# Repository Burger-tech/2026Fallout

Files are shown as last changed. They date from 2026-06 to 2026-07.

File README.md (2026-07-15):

# Our 2026 HackClub Fallout Project
Presented by Tyler Bergsma and Andy He (With a TON of CAD help from Keegan O'Neil)

## Our Project

We decided to make a Nerf Rival shooting mecanum-drive differential-turret robot that has auto aiming built in. This came from a love of robotics from all of us, and also because we all enjoy Nerf battles and guns.  Here's an example of what we wanted the turret to look initially: 

whatwewanted

This is what our original thought concept was considering the features we wanted for our bot.

The next most meaningful part of the robot is the drivetrain, which we decided would use mecanum wheels to give our robot incredibly diverse and versatile movement. Paired with the strong 600RPM motors we plan to use, this should give us a very snappy and responsive bot. 
Because our robot will be mostly 3d-printed out of PETG, it should be very durable, and the underlying frame (made of aluminum) brings that up even more.
Our camera system on the robot should also be extremely robust, using 3 cameras in total- 2 for general operator vision and 1 to give an onbaord raspberry pi access to auto-aiming features so that the robot can aim fully autonomously. We plan to send the camera input back to Tyler's Steamdeck OLED for processing and for human controller input. Speaking of sending information back and forth, the robot will use a 2.4Ghz WiFi adapter to connect to a local network and allow it to stream video and control signals back and forth. This gives us extremely low latency and high quality video, as well as the added benefit of being able to possibly be connected to LTE farther down the line and be controlled from anywhere in the world.
To shoot the Rival rounds, we plan to use two flywheels and shoot them around ~110-120fps in total, giving them some kick for a relatively short spin up time and a small amount of downtime per shot.

Here's a picture of our full 3D model (done in onshape), to show what we mean by all that:

2026-06-16-220244_hyprshot

2026-06-16-220259_hyprshot

2026-06-16-220311_hyprshot

2026-06-16-220324_hyprshot

2026-06-16-220334_hyprshot

CAD OnShape Link: https://cad.onshape.com/documents/071289950c39e2528783d758/w/1973af73cf652c9bb88bcb7f/e/c3e7d5f0022195b47dc63524

And here's a screenshot of the base chasis that we plan to use:

base chasis

## Our Process

A full Bill of materials (BOM) can be found at the resources section at the bottom of our README.
To start off, first we figured out the major components we would use in our project and what mechanisms or devices we would use to bring our bot to life. This included creating a list of all of the parts we need with links, so that we'd also hopefully be able to find their dimensions and other specs. This took only around and hour with some very intensive googling and queries to Claude.
The next most important task was to CAD it upp! Our amazing half-team-member Keegan the CAD monster did all of this, creating the whole external structure of the bot including all of the mounts and such in OnShape.
Once our project gains monetary approval, we plan to 3D-print all of the parts we need from various colors of PETG on Tyler's A1-Mini and Ender-3. We also hope to possibly use the P2S in our robotics team lab to hopefully be able to print some of the larger parts quickly.

## US!

There are three of us working on this project. We are Tyler Bergsma, Keegan O'Neil, and Andy He. Unfortunately, Keegan won't be coming with us to Shenzen, but he was an AMAZING help to our lackluster CAD abilities. We're all from Denver, Colorado, U.S.A., and we all attend Chatfield Senior High, where we are a part of the schools local FIRST robotics team, [The Chargers (Team 9068)](https://Chatfieldrobotics.org). All three of us love robotics and mechanical/programming stuff, which is a huge part of why we chose to do what we did with this event. 

## BOM

- Drivetrain
    - JGB37-520 12V 600 RPM Motors
| Quantity: 4 | Price: $8.38 | Total: $33.52
    - BTS7960 43A H-Bridge Motor Driver
| Quantity: 1 (4 pack) | Price: $24.89 | Total: $24.89
    - 60mm Mecanum Wheel Omnidirectional Wheel Smart Robot Car Chassis with TT Motor N20G25
| Quantity: 1 (4 pack) | Price: $9.48 | Total: $9.48
    - SUNLU High Speed PETG Filament 1.75mm Bundle, Less Stringing PETG 3D Printer Filament, 2kg in Total, 1kg per Spool, 2 Pack, Blue+Red
| Quantity: 1 (2kg) | Price: $25.64 | Total: $25.64
    - ZDF Lipo battery 3S 11.1V 5000mAh 6000mah 8000mah 10000mah 12000mah 16000mah 25C 30C 50C For RC Helicopter Quadcopter
| Quantity: 1 | Price: $46.69 | Total: $46.69
    - GA12 N20 Encoder DC 6V Mini Micro Metal Gear DC Motor Gearwheel High Torque 100 RPM 7PPR Hall Sensor
| Quantity: 3 | Price: $0.99 | Total: $2.79
    - Emax ECO II Series 2306 1700KV 1900KV 2400KV Brushless Motor for RC FPV Drone Racing Quadcopter Spare Parts RC Parts
| Quantity: 1 (2 pack) | Price: $25.46 | Total: $25.46
    - TB6612 DRV8833 Dual Motor Driver 1A TB6612FNG for Arduino Microcontroller Better than L298N
| Quantity: 1 (3 pack) | Price: $0.99 | Total: $0.99
    - LittleBee 20A 30A BLHeli-S ESC Support DSHOT OneShot For 2-6S FPV Quadcopter
| Quantity: 1 (4 pack) | Price: $31.62 | Total: $31.62

- Electronics
    - Raspberry Pi Zero 2 WH Kit
| Quantity: 1 | Price: $41.99 | Total: $41.99
    - Wi-Fi USB Dongle Adapter with Gain Antenna – Plug & Play for Linux (Tails, Ubuntu, Debian, Fedora, Mint, Arch) + Windows 11/10/8/7, Android & Mac | 2.4 GHz MT7601U Chipset 150 Mbps
| Quantity: 1 | Price: $17.99 | Total: $17.99
    - Arducam 5MP Camera for Raspberry Pi, 1080P HD OV5647 Camera Module V1 for Raspberry Pi5/4/3/3B+, and Other A/B Series
| Quantity: 1 (maybe 2-4) | Price: $6.99 | Total: $6.99
    - ESP32-CAM WiFi Module 2.4G Antenna ESP32 Serial to WiFi ESP32 CAM Development Board 5V Bluetooth with OV3660 / OV2640 Camera DIY
| Quantity: 2 | Price: $6.46 | Total: $12.92
    - Official Raspberry Pi Pico Board RP2040 Dual-Core 264KB ARM Low-Power Microcomputers High-Performance Cortex-M0+ Processor
| Quantity: 3 | Price: $0.99 | Total: $2.79
    - 1-10pcs PCA9685PW 16 Channel 12-Bit PWM Servo Shield Driver I2C Interface PCA9685 Module For Raspberry Pi
| Quantity: 1 | Price: $0.99 | Total: $0.99
    - 2-8PCS LM2596 Step-down Power Supply Module 3A 3.2V-46V DC to DC Voltage Regulator Module Buck Converter Power Supply Modules
| Quantity: 1 (4 pack) | Price: $9.26 | Total: $9.26
    - AC 220V 250RPM 300RPM 6 Channel 6 wires Capsule Slip Ring CIRCUITSx2A Slipring 12.5/22MM Mini Rotary Conductive Joint Connectors
| Quantity: 1 | Price: $0.99 | Total: $0.99
    - 14AWG XT60 Female Male Plug Battery Connector with Silicone Flexible Wire for RC Airplane Lipo Battery ESC FPV Drone Car Boat | Quantity: 1 (10 pack)
| Price: $12.50 | Total: $12.50
    - 5 Colors Flexible Silicone Wire 16 AWG Gauge Tinned Copper Stranded Wire 300V Cables Electronic Wire Cable
| Quantity: 1 (5 colors, 4 meters) | Price: $9.30 | Total: $9.30
    - 5 Colors Flexible Silicone Wire 22 AWG Gauge Tinned Copper Stranded Wire 300V Cables Electronic Wire Cable
| Quantity: 1 (5 colors, 10 meters) | Price: $0.99 | Total: $0.99

- Others
    - 25V DIP Aluminum Electrolytic Capacitor 100UF
| Quantity: 1 (40 pack) | Price: $0.99 | Total: $0.99
    - POKONBOY 300 Rounds Refill Pack Balls Ammo Compatible with Nerf Rival Gun, Foam Bullet Ball Replacement Refill Pack for Blasters Guns
| Quantity: 1 (300 count) | Price: $24.99 | Total: $24.99
    - 0.5" Hex Shaft Collars
| Quantity: 5 | Price: $2.99 | Total: $14.95
    - 0.500" Hex ID x 1.125" OD x 0.313" WD (Flanged Bearing) (WCP-0783)
| Quantity: 4 | Price: $2.99 | Total: $11.96
    - OV2640 160 degrees 850nm night version 940nm camera module 21MM 24PIN 0.5MM spacing
| Quantity: 1 | Price: $0.99 | Total: $0.99
    - 10/50pcs Small Bearings 2mm 3mm 4mm 5mm 6mm 7mm 8mm 9mm 10mm Bore 3x7x3 5x10x4 5x11x4 8x22x7 10x15x4 mm Miniature Bearing
| Quantity: 20 (10 8x12x3.5mm and 10 15x21x4mm| Price: $0.99 | Total: $0.99
    - 5Pcs 6903RS 12x28x8mm Motor Grade Cover Sealed Deep Groove Ball Bearing RS 52100 Chrome Steel ABEC-7
| Quantity: 1 (5 pack 6903RS 17x30x7) | Price: $0.99 | Total: $0.99
    - 1/2in Rounded Hex Shafts
| Quantity: 1 | Price: $10.50 | Total: $10.50
    - 4Pcs 6mm Coupling
| Quantity: 1 (4 pack) | Price: $0.82 | Total: $0.82

Total Cost: $382.41

## Zine Page
Turret Bot Zine Page (1)

## How to Replicate and Understanding

Ratios:
Base Differential gears: 5:1or 125:25
Internal to external: 102:27 or 34/9:1
Bevel gears: 1:1 or 20:20
Angle control: 100:16 or 6.25:1

coaxial/differential explanation:
The differential turret consists of two base gears, with one gear having only external teeth, and the other having both external and internal teeth. A separate gear is mounted to the gear that only has external teeth, but it is driven by the gear that has both internal and external gears. The gear that gets driven internally directly drives a bevel gear. This bevel gear drives another bevel gear that is mounted to a shaft that is mounted on the base gear with only external teeth. Also mounted on that shaft is two normal spur gears that end up driving the turret that is also mounted on the base gear with only external teeth. 

Turret:
The turret consists of a camera for object detection and auto aiming with the coaxial gear system, two flywheels that are directly driven by brushless motors, an agitation motor and wheel to prevent jams, and a hopper to hold bullets. The bullets that the hopper holds feed into a square funnel that also leads into a rectangular funnel shouldn’t jam due to an agitation motor. The rectangular funnel feeds into a single stream that is prevented from getting jams due to the flywheel also acting as an agitation wheel. These bullets eventually feed through into the flywheels, which have 0.175 inches of compression on the bullets, to eventually get shot at a specific target.

How to replicate:
For the overall robot, you will want to determine all the electronic and mechanical components you will be using, then determine where and how you want them mounted. For the drive base, you will want to figure out what kind of driving system you want to use (mecanum, swerve, or something else), then create a master sketch of the side view and the top view of how you want the overall layout to look. The group decided that our shooting mechanism would be a coaxial turret, and that we would be using mecanum wheels to drive the robot so we could get omnidirectional mobility. Once you have your overall design picked and drawn out, you should start out with the drivetrain, which you will design around the parts list and the master sketch. For your drivetrain, you will need to mount out where all the electronics and maybe some mechanical things will be located/mounted and how they will be mounted so you need to create space for that. This includes things such as your motors, the overall brain potentially, wire management, battery, motor controllers, buck converters, cameras, wheels, and much more. We personally decided to mount all electronics other than 3 motors, pi cam, and the pi zero, which we mounted to the turret itself. The pi zero and camera serve as components directly linked object detection cam and brain and the motors control the flywheels. Once you have the method for mounting everything, and you have the overall design finished for the drivetrain, you can move on to the shooter. As previously stated, we went with a coaxial turret. To start out, decide what ratios and tooth counts you want for the gears driving the turret angle and position. We used a 5:1 for each base gear. You will also want to determine how you will feed the shooter itself. We went with a funnel indexing system that had 2 points of agitation to prevent jamming. You will also need to keep in mind the assembly. I would have run into a bunch of assembly errors if I hadn’t triple checked my work, so be careful about that. Finally, once you have the drivetrain and turret mechanism figured out, you can add tolerances and put it all together into an assembly to make sure everything packages without any problems.

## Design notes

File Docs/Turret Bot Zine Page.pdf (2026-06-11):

## HHaavvee yyoouu eevveerr wwaanntteedd ttoo Have you ever wanted to

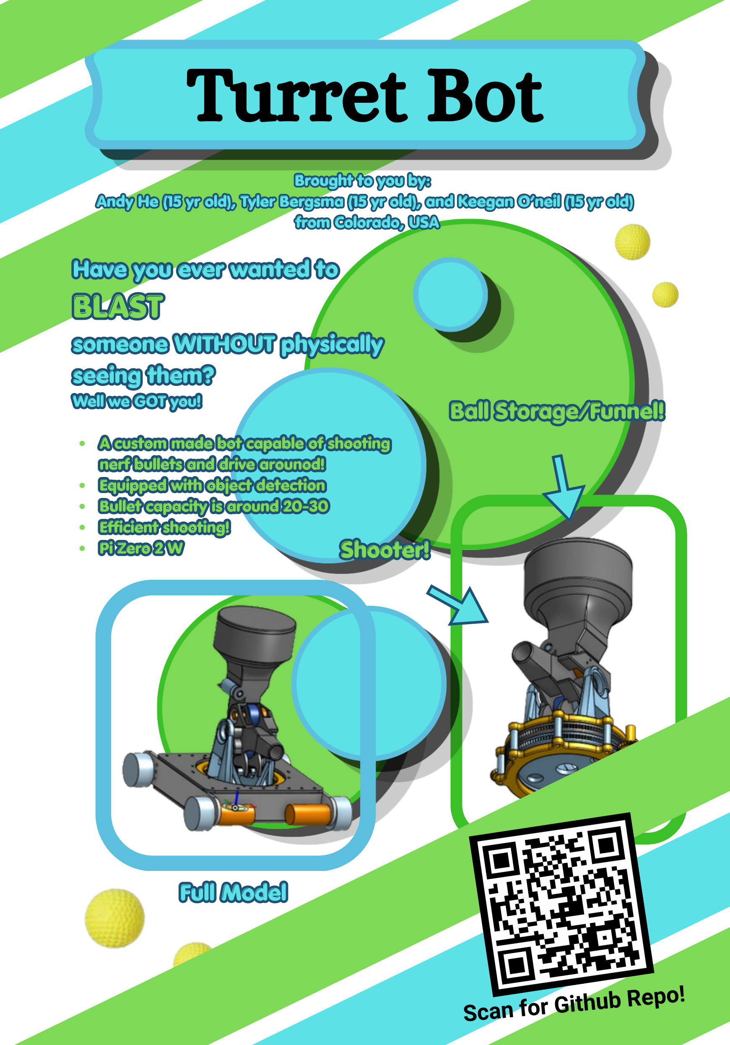
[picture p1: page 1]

# BLAST

## someone WITHOUT physically seeing them?

## Well we GOT you!

A custom made bot capable of shooting nerf bullets and drive arounod!

## Equipped with object detection Bullet capacity is around 20-30 Efficient shooting! Pi Zero 2 W

# BLAST

## someone WITHOUT physically seeing them?

Well we GOT you!

A custom made bot capable of shooting nerf bullets and drive arounod! Equipped with object detection
Bullet capacity is around 20-30 Efficient shooting!
Pi Zero 2 W

# Turret Bot

# Scan for Github Repo!

Brought to you by: Andy He (15 yr old), Tyler Bergsma (15 yr old), and Keegan O’neil (15 yr old) from Colorado, USA

Brought to you by:
Andy He (15 yr old), Tyler Bergsma (15 yr old), and Keegan O’neil (15 yr old) from Colorado, USA

## Ball Storage/Funnel!

## SShhooootteerr!!

## Full Model

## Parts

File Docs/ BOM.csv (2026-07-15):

 | Price | Quantity | Link | Total | Extra Info
Motors - JGB37-520 12V 600rpm motors | $13.49 | 4 | https://www.aliexpress.us/item/3256806061912139.html?curPageLogUid=VOXo4eoKJxvt | $53.96 | The 4 drivers for our mecanum motors below (1 per bc it's mecanum)
Motor controller - BTS7960 43A H-Bridge Motor Driver | $15.80 | 1 (4 pack) | https://www.aliexpress.us/item/3256811525663988.html?curPageLogUid=e8hDJZGhOjv2 | $15.80 | Maybe spare controllers if we can as well
Mecanum wheels | $3.04 | 4 | https://www.aliexpress.us/item/3256805517440779.html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 | $12.16 | The wheels
2kg PETG (Blue and red) | $27.99 | 1 (2kg) | https://www.amazon.com/SUNLU-High-Speed-Filament-1-75mm/dp/B0F5VLQZS6 | $27.99 | grey, we can use additional colors we have on hand as well
3S 6k Mah XT60 Lipo | $42.19 | 1 (more if budget allows) | https://www.aliexpress.us/item/2251832781216386.html?curPageLogUid=mBmPmCXIAXAl | $42.19 | We could definetly use more if we can get more to minimize downtime
6V Mini 100rpm motor | $0.99 | 3 | https://www.aliexpress.us/item/3256807284283899.html?curPageLogUid=yYGfik5Fk3CM | $2.97 | The 2 motors we need for our diffy turret and one extra for the hopper pusher/puller motor
2306 2400KV Flywheel Motors | $25.91 | 1 (2 pack) | https://www.aliexpress.us/item/3256805556527512.html?curPageLogUid=uC9aGJpYmplU | $25.91 | 2 flywheel motors for the shooter
TB6612 dual motor driver | $0.99 | 1 (3 pack) | https://www.aliexpress.us/item/3256809678442187.html?curPageLogUid=I5mvHZIIYxf0 | $0.99 | Motor drivers for the two diffy's and one for the pusher
BLHeli-S ESC 30amp drivers | $32.10 | 1 (4 pack) | https://www.aliexpress.us/item/3256811683435931.html?curPageLogUid=WTVh1L2qrCoV | $32.10 | The drivers for the flywheels (two more than we need but better safe than sorry). Also around 10 amps of breathing room so more than enough for our application
Pi Zero W | $31.99 | 1 | https://www.amazon.com/EC-Buying-Pi-Zero-Development/dp/B0FN4CN7TM/ref=sr_1_2?sr=8-2 | $41.99 | The main processor for OpenCV (vision and object detection)
MT7601U WiFi Dongle | $17.99 | 1 | https://www.amazon.com/Wi-Fi-Dongle-Adapter-Gain-Antenna/dp/B0FXN1ML7Y/ref=sr_1_1?sr=8-1 | $17.99 | WiFi adapter for the pi so that we can get drastically better range
HD OV5647 Camera Module | $6.99 | 1 (maybee 2) | https://www.amazon.com/Arducam-Megapixels-Sensor-OV5647-Raspberry/dp/B012V1HEP4/ref=sr_1_1?sr=8-1 | $6.99 | The main aiming camera for the pi
ESP32-CAM type c with antenna | $1.24 | 2 | https://www.aliexpress.us/item/3256808866325459.html?curPageLogUid=P5JUHPVKMVKv | $2.48 | Rear and high views for the user to view (not used in auto aiming). Aggregated to the main pi zero then sent to steamdeck
Pi Pico | $0.99 | 3 | https://www.aliexpress.us/item/3256805430865417.html?curPageLogUid=8KjMoAkO2VwC | $2.97 | The main bus controller for raw instructions to the drivers plus 2 extra bc they're cheap asf
PWM Board PCA9685 | $0.99 | 1 | https://www.aliexpress.us/item/3256808530862929.html?curPageLogUid=Q8JqVWKOUM6N | $0.99 | Extra lanes of PWM if we need it for more motors (hopefully won't need at all)
LM2596 Buck Converter | $0.99 | 1 (3 pack) | https://www.aliexpress.us/item/3256808194722756.html?curPageLogUid=D5wD63BSWnOX | $0.99 | The buck converters we need for the raspberry pi's and esp32 Cams
Wire slip ring (250rpm, 6 wire) | $0.99 | 1 | https://www.aliexpress.us/item/2255800984259333.html?curPageLogUid=JUVALdfGF3MK | $0.99 | Slip ring allows us to have full rotation for our turret like a tank
xt60 connectors (10 male, female) | $21.35 | 1 (10 pack) | https://www.aliexpress.us/item/3256810183858580.html?curPageLogUid=71iEgc8rjSQR | $21.35 | So that we can connect the battery and make our bot accessable to take apart and work on
16AWG wire | $9.30 | 1 (5 colors, 4 meters) | https://www.aliexpress.us/item/3256807070653563.html?curPageLogUid=HP400qLLtaQc | $19.87 | Motor wiring with 5 different colors (anything more than signals really)
22AWG wire | $6.80 | 1 (5 colors, 10 meters) | https://www.aliexpress.us/item/3256807070653563.html?curPageLogUid=HP400qLLtaQc | $6.80 | Signal wiring for PWM and pi zero to pi pico for motor control and from pico to motor drivers I believe
25V 100UF capacitors | $0.99 | 1 (40 pack) | https://www.aliexpress.us/item/3256811445656016.html?curPageLogUid=HMtMCpdzrivN | $0.99 | To level out the motor spikes and dips
300 Rival Rounds | $24.99 | 1 (300 count) | https://www.amazon.com/POKONBOY-Rounds-Refill-Rival-Compatible/dp/B07RK6JGKN?sp_csd=d2lkZ2V0TmFtZT1zcF9hdGY | $24.59 | The Ammo
0.5" hex shaft collars | $17.45 | 5 in total | https://wcproducts.com/products/clamping-shaft-collars | $14.95 | to keep the bearings from slipping out
0.5" hex bearings | 11.96 | 4 in total | https://wcproducts.com/collections/cnc-hardware/products/ball-bearings | $11.96 | bearings
21MM 160 degrees camera | $0.99 | 1 | https://www.aliexpress.us/item/3256803720134565.html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 | $0.99 | camera so we can cover a greater area visually
more bearings | $0.99 | 20 (10x8,12,3.5)(10x15,21,4) | https://www.aliexpress.us/item/3256807482131308.html?curPageLogUid=qPF1uG5KvbMZ | $0.99 | more bearings
more of another type of bearing |  | 5 (17,30,7) | https://www.aliexpress.us/item/3256805856699678.html?curPageLogUid=Jt1F8pvUO16M | $0.99
hex shaft stock | $10.50 | 10 in | https://www.revrobotics.com/.5in-Rounded-Hex-Shafts/?searchid=5397175&search_query=hex | $10.50 | hex shaft for sturctural support and to drive some gears
hex couplers | $0.82 | 1 (4 pack | https://www.aliexpress.us/item/3256805517440779.html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 | $0.82 | it is the coupler that links our motors to the wheels
Aluminum sheet stock | 21.99 | 1 | https://www.amazon.com/ACXFOND-Aluminum-Thickness-Protective-Industry/dp/B0CG5DZCBL?adgrpid=193180835944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 | 21.99 | aluminum for plate
12x12 aluminium sheet | 19.99 | 1 | https://www.amazon.com/Aluminum-Sheet-Rectangle-Plate-Protective/dp/B0BZPL1D4K?adgrpid=193180835944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 | 19.99 | different sized aluminum plate
different sized aluminum sheet | 24.99 | 1 | https://www.amazon.com/Tynulox-Aluminum-Protective-Treatable-Industry/dp/B0CW997S6B?s=industrial | 24.99 | more aluminum for plates
 |  |  |  | Grand Total:
 |  |  |  | $471.23

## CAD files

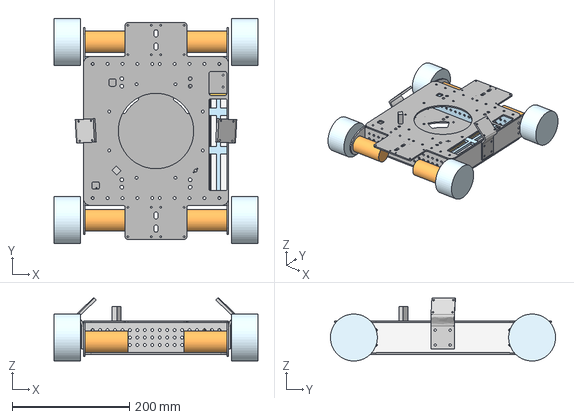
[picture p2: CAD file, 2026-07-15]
CAD/MecanumDriveTrain.step
347.6 x 383.7 x 107.3 mm

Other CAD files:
CAD/CoaxialTurret.step

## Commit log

2026-06-10 Update README with base chassis screenshot
    Added a screenshot of the base chassis to the README.
2026-06-10 Add BOM section to README
    Added Bill of Materials (BOM) section with components.
2026-06-10 Revise BOM with quantities and pricing details
    Updated BOM section with detailed quantities and prices for components.
2026-06-10 Improve formatting of BOM section in README
    Reformatted BOM section for better readability.
2026-06-10 Fix formatting in BOM section of README.md
2026-06-10 Add CAD OnShape link to README
    Added CAD OnShape link to the README for reference.
2026-06-12 Replace images and add CAD OnShape link in README
    Updated images in README with new assets and added CAD link.
2026-06-21 Expand instructions on replication and turret mechanics
    Added detailed explanations of ratios, gear systems, and turret components for replication.
2026-07-15 Rename mecanum drivetrain.step to MecanumDriveTrain.step
    [MecanumDriveTrain.step]
2026-07-15 Rename coaxial turret.step to CoaxialTurret.step
    [CoaxialTurret.step]
2026-07-15 Add BOM.csv for project budget tracking
    [BOM.csv]
2026-07-15 Create BOM
2026-07-15 Add MecanumDriveTrain step file
    [MecanumDriveTrain.step]
2026-07-15 Rename Fallout Project Budget_Costs - Sheet1 (1).csv to BOM.csv
    [BOM.csv]
